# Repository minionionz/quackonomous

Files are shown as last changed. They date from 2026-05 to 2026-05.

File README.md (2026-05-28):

# Hackaburg 2026

# Projekt Quackonomous

---

## Vision

Eine gewöhnliche Gummiente wird zum autonomen Wasserfahrzeug, gesteuert durch Embedded-Logik, navigiert selbstständig oder per Fernsteuerung.

Meilenstein 1: Ente mit Fernbedienung steuern (USB Modul, Steuerelement, ESP now)

Meilenstein 2: Hilfssysteme (Ultraschallsensor, e.g. Hindernis voraus: bremsen)

---

## Thema & Scope

| Bereich | Beschreibung |
| --- | --- |
| Fahrzeug | Gummiente mit Antrieb + Ruder |
| Steuerung | Autonom + manuelle Fernsteuerung |
| Domäne | Embedded Systems / Robotik |
| Hardware | Vollständig vorhanden  |

---

## Phasenplan

| Phase | Fokus | Status |
| --- | --- | --- |
| 1 — Setup | Hardware checken, Rollen verteilen | done |
| 2 — Core | Antrieb + Fernsteuerung |  |
| 3 — Autonomie | Sensorik + Navigation |  |
| 4 — Demo | Test, Pitch, Puffer |  |

---

## Aufgaben

### Phase 1 — Setup

- [x]  Hardware-Inventur: welche Komponenten sind da?
- [ ]  Rollen im Team verteilen
- [x]  Repo + Projektstruktur aufsetzen

### Phase 2 — Core

- [ ]  Antriebstest — Motor + Ruder auf Funktion prüfen
- [ ]  Microcontroller / SBC aufsetzen (Firmware / OS)
- [ ]  Fernsteuerung implementieren (Bluetooth / RF / WLAN)

### Phase 3 — Autonomie

- [ ]  Sensorik einbinden (Ultraschall / Kamera / GPS?)
- [ ]  Autonome Navigationslogik entwickeln
- [ ]  Wassertauglichkeit / Abdichtung prüfen

### Phase 4 — Demo

- [ ]  Demo-Lauf testen
- [ ]  GitHub README schreiben

---

## Team-Rollen

| Rolle | Verantwortung | Person |
| --- | --- | --- |
| Hardware / Mechanik | Antrieb, Verkabelung, Wasserdichtigkeit |  |
| Embedded / Firmware | Microcontroller, Treiber, Low-Level |  |
| Software / Autonomie | Navigationslogik, Sensorauswertung |  |
| Fernsteuerung / Protokoll | Kommunikation, RC-Interface |  |
| Präsentation / Doku | Demo, Pitch, README |  |

---

## Offene Fragen & Risiken

- [ ]  Stromversorgung im Wasser — Akku-Laufzeit?
- [ ]  Latenz bei Fernsteuerung akzeptabel?
- [ ]  Wie wird der Kurs definiert? (GPS-Wegpunkte / Linienverfolgung / Kompass)

---

## Links & Ressourcen

- Hardware-Doku:
- Hackathon-Regeln / Einreichung:

---

## Notizen

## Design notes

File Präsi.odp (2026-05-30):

## Quackonomous

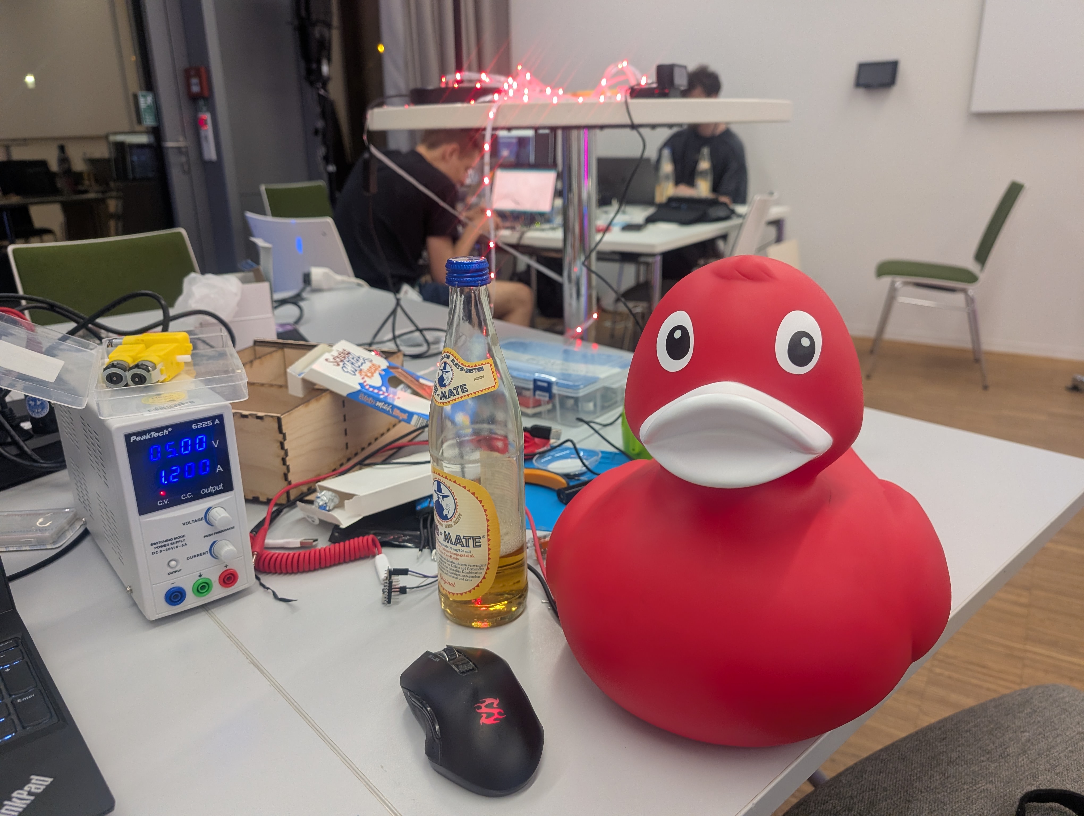
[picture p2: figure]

## Dual Motor Design

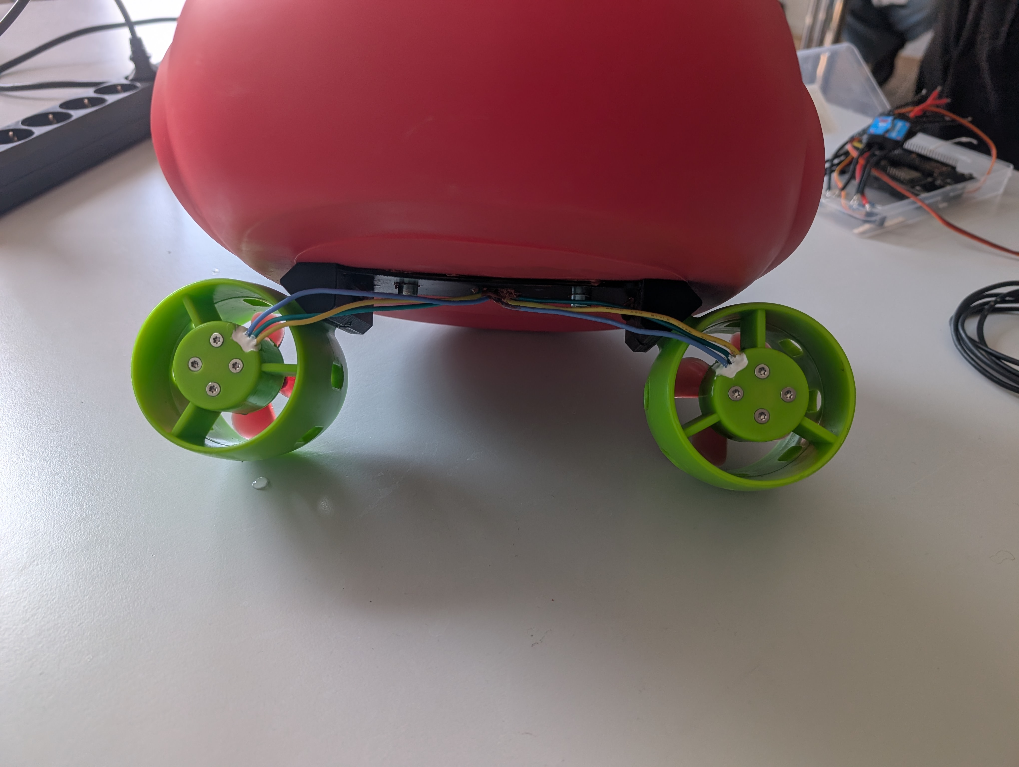
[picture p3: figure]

- Double 30A ESC
- 888W Total Motor Power

## Duck Vision

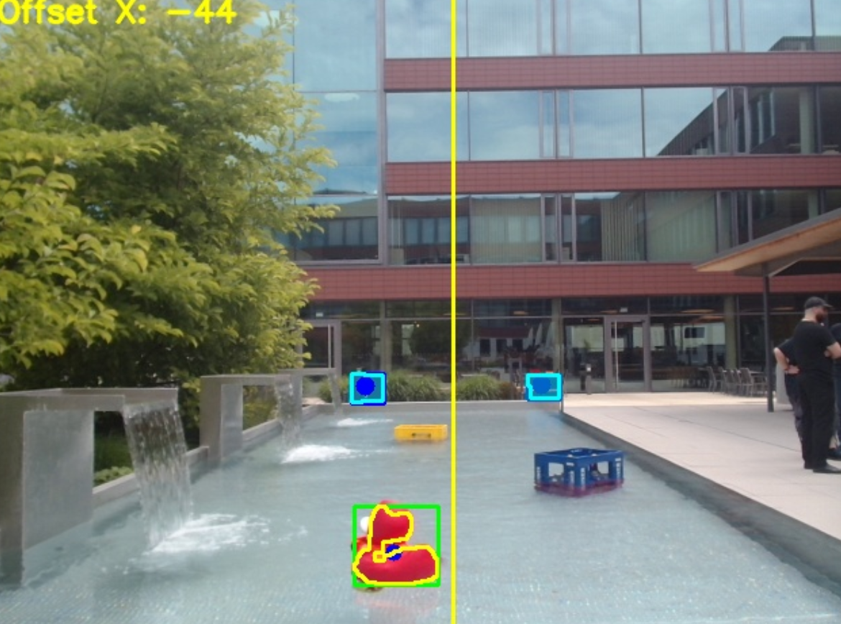
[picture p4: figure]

- Two Target Markers
- Duck Tracking
- Target Determination

## Metric Analytics

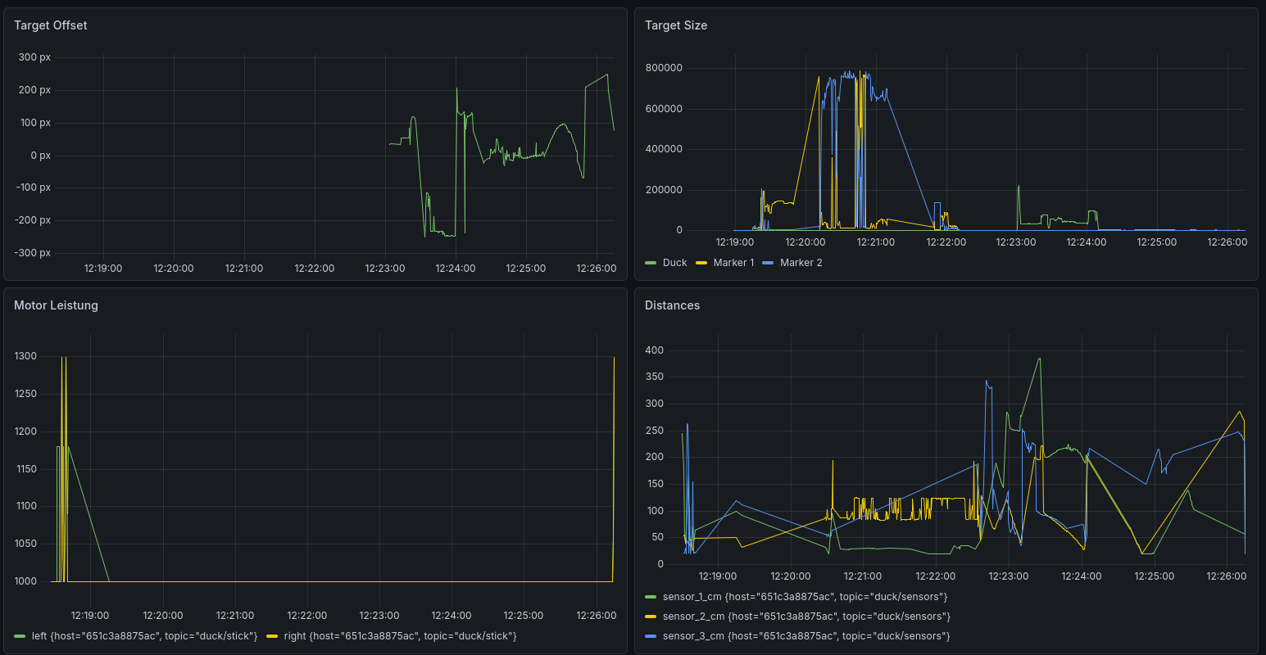
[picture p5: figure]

- Mosqitto MQTT
- Telegraf
- Influxdb
- Grafana

## Ultrasonic Distance Sensors

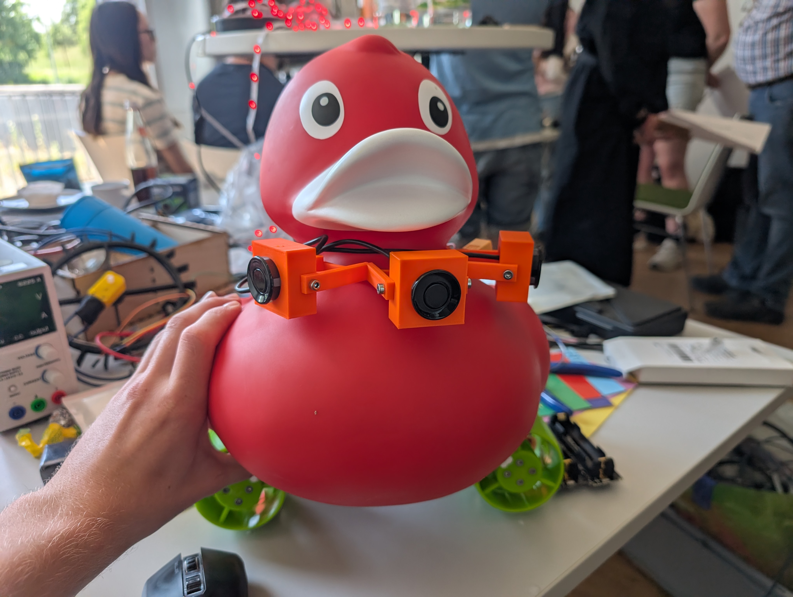
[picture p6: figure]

## Backflip capability

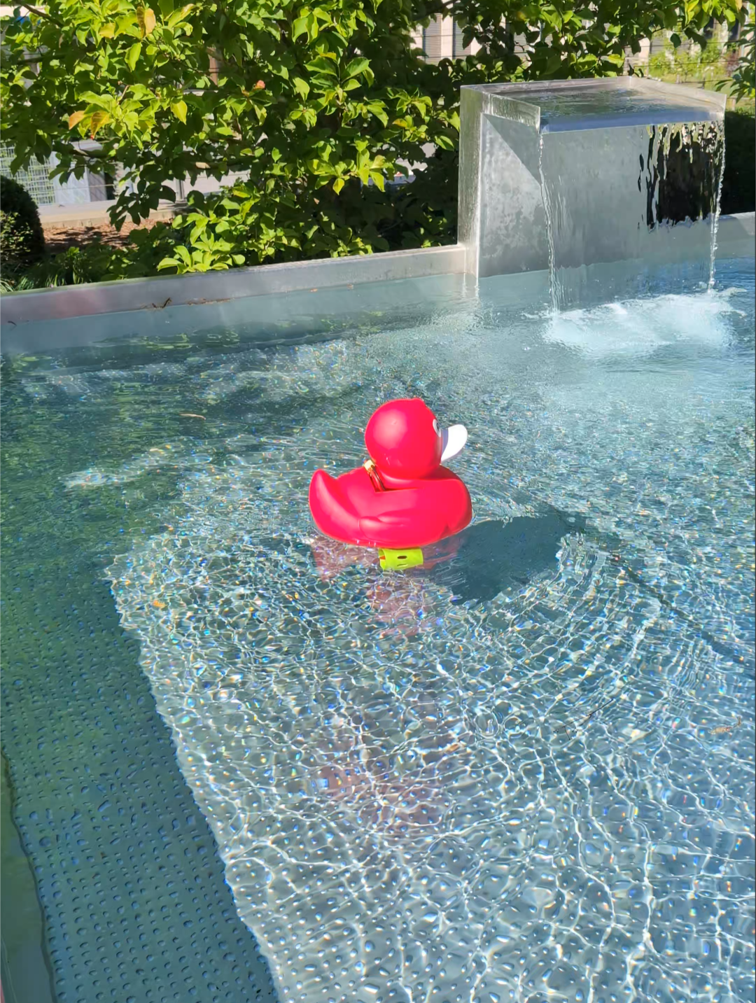
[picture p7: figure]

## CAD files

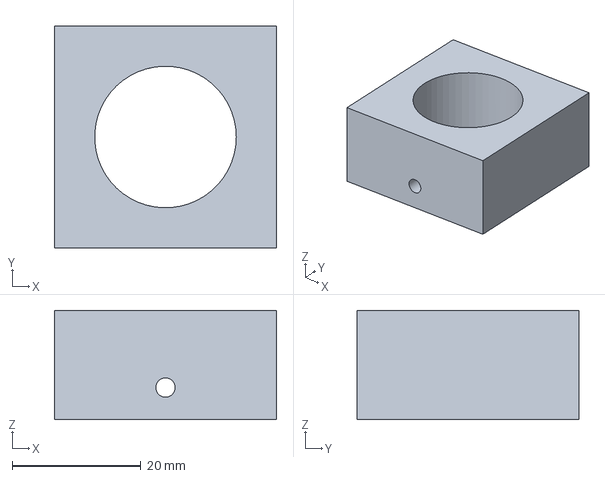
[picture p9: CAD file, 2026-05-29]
3D Teile/Enten Halsband/Halsband.FCStd
34.5 x 34.5 x 17.0 mm

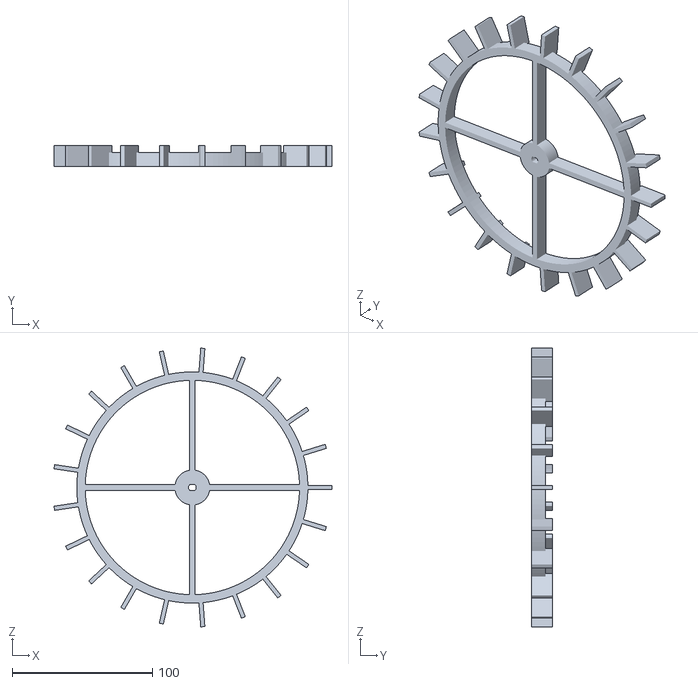
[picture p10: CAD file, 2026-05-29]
3D Teile/Schaufelräder/Schaufelrad.stl
198.5 x 15.0 x 199.0

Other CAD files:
3D Teile/Enten Halsband/Sensor-Halterung.stl
3D Teile/Schaufelräder/Schaufelräder.FCStd
3D Teile/Enten Halsband/Halsband.stl

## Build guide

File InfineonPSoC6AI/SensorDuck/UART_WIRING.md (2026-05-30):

# UART WIRING
## Wiring PSoC6 → ESP32 Feather:
```
┌────────────────────────┬─────────────────┬────────────────────────────────┐
│   CY8CKIT-062S2-AI     │  ESP32 Feather  │              Note              │
│    (Arduino header)    │                 │                                │
├────────────────────────┼─────────────────┼────────────────────────────────┤
│ P9_1 (Arduino D1)      │ Any free RX pin │ PSoC TX → ESP RX               │
│                        │  (e.g. GPIO16)  │                                │
├────────────────────────┼─────────────────┼────────────────────────────────┤
│                        │ Any free TX pin │ PSoC RX ← ESP TX (optional,    │
│ P9_0 (Arduino D0)      │  (e.g. GPIO17)  │ only needed if ESP sends       │
│                        │                 │ commands back)                 │
├────────────────────────┼─────────────────┼────────────────────────────────┤
│ GND                    │ GND             │ Required — common ground       │
└────────────────────────┴─────────────────┴────────────────────────────────┘
```

Both sides are 3.3 V logic so no level shifting needed. On the ESP32 side use Serial2.begin(115200) and read lines with Serial2.readStringUntil('\n'), then parse with ArduinoJson. The "imu":true,"mag":true fields let you skip malformed packets.

## How do I parse this on the ESP32 side?

### platformio.ini
Use ArduinoJson. Add it to Firmware Duck/platformio.ini:
```YAML
lib_deps =
    bblanchon/ArduinoJson@^7
```

### Sketch
Then in your sketch:

```C
#include <Arduino.h>
#include <ArduinoJson.h>

// ── Feather ESP32 (classic HUZZAH32): GPIO16/17 are fine
// ── Feather ESP32 V2: GPIO16 = PSRAM — use something else, e.g. GPIO27/33
#define PSOC_RX_PIN 16
#define PSOC_TX_PIN 17

static char     _rxbuf[256];
static uint16_t _rxpos = 0;

void setup() {
    Serial.begin(115200);

    // Must be called BEFORE begin() — doubles the default RX buffer
    Serial2.setRxBufferSize(512);
    Serial2.begin(115200, SERIAL_8N1, PSOC_RX_PIN, PSOC_TX_PIN);
}

void onSensorLine(const char* line) {
    JsonDocument doc;
    if (deserializeJson(doc, line) != DeserializationError::Ok) {
        Serial.println("bad json");
        return;
    }
    if (!doc["ok"]["imu"] || !doc["ok"]["mag"]) return;

    float heading = doc["mag"]["hdg"];
    float gyro_z  = doc["imu"]["gyro"]["z"];
    // … use values
    Serial.printf("hdg=%.1f  gyro_z=%.2f\n", heading, gyro_z);
}
<<<<<<< Updated upstream
=======

void loop() {
    // Drain everything available this tick — never blocks
    while (Serial2.available()) {
        char c = (char)Serial2.read();

        if (c == '\n') {
            // Strip trailing \r if present
            if (_rxpos > 0 && _rxbuf[_rxpos - 1] == '\r') _rxpos--;
            _rxbuf[_rxpos] = '\0';

            if (_rxpos > 0) onSensorLine(_rxbuf);
            _rxpos = 0;

        } else if (_rxpos < sizeof(_rxbuf) - 1) {
            _rxbuf[_rxpos++] = c;

        } else {
            // Line longer than buffer — discard and resync
            _rxpos = 0;
        }
    }

    // … rest of your loop (motors, ESP-NOW, etc.)
}
>>>>>>> Stashed changes
```

A few things to note:

- readStringUntil('\n') blocks until it sees \n — the PSoC sends \r\n so trim() strips the trailing \r.
- Check doc["ok"] before using values — during the first ~500 ms after boot the sensors may not be ready yet.
- JsonDocument (no size parameter) is ArduinoJson 7. If you're on v6 use StaticJsonDocument<256> doc; instead.
- For steering you'll mostly care about mag.hdg (where are we pointing) and imu.gyro.z (how fast are we turning). The accel and mag field X/Y/Z are there when you want tilt compensation later.

<<<<<<< Updated upstream
## Magnet data hints

### Why does mag.field have X/Y/Z?

The magnetometer measures the full 3D magnetic field vector, not a heading directly. Heading is computed as atan2(field.y, field.x) — but that formula only gives the correct compass bearing when the board is perfectly flat. The moment the duck tilts (waves, acceleration), the answer drifts.

field.z (the vertical dip component) lets the ESP32 do tilt-compensated heading by combining all three magnetic field components with the IMU accelerometer. The formula rotates the magnetic vector out of the tilted frame back into the horizontal plane before computing the angle. Without Z you can't do that.

So the short version: hdg is the fast and easy bearing, fine for calm water. If you want accurate heading while the duck is rocking, the ESP32 can compute a corrected heading from field.x/y/z + imu.accel.x/y/z.
=======
## Thoughts about "Regelung"
❯ Can we use the degree data and its derivative to differentiate degree changes coming from floating on the water from degree changes coming from turning left or right? Is this a good way to differentiate these two kinds of motions or are there better ones (we only want to counteract drifts to the sides while driving and not the usual floating)?

Good question, and the honest answer is: not reliably using those two signals alone. Here's why, and what actually works.

Why heading + turn rate isn't enough

Both drift and intentional turning produce the same signature in those signals — a changing heading and a non-zero turn rate. You could try a threshold ("if turn rate < 3 °/s it's drift, if > 10 °/s it's intentional"), but this breaks whenever:
- You command a slow, gentle correction turn
- A strong current or wind causes fast drift
- Waves make the heading oscillate rapidly at small amplitude

What actually distinguishes them

The real discriminator is whether you commanded the motion. The signal you're missing is the motor/steering output. Once you know that:

┌──────────────────────────┬────────────────────┬────────────────────────────────────────────────┐
│        Situation         │ Commanded steering │            Gyro.z / heading change             │
├──────────────────────────┼────────────────────┼────────────────────────────────────────────────┤
│ Going straight, no drift │ ~zero              │ ~zero                                          │
├──────────────────────────┼────────────────────┼────────────────────────────────────────────────┤
│ Going straight, drifting │ ~zero              │ non-zero ← this is what you want to counteract │
├──────────────────────────┼────────────────────┼────────────────────────────────────────────────┤
│ Intentional turn         │ non-zero           │ non-zero (expected)                            │
├──────────────────────────┼────────────────────┼────────────────────────────────────────────────┤
│ Turn complete, coasting  │ ~zero              │ small residual                                 │
└──────────────────────────┴────────────────────┴────────────────────────────────────────────────┘

Drift is simply unexpected heading change — motion that occurs without a corresponding steering command.

The standard solution: heading hold

Instead of classifying motion, just hold a target heading. This sidesteps the problem entirely:

# Pseudocode on the ESP32 side

```C
target_hdg = None   # set once duck starts straight-line driving

def loop():
    current_hdg = read_psoc_heading()
    joystick_turn = read_joystick_x()

    if joystick_turn != 0:
        # Intentional turn: don't fight it, update target when done
        apply_steering(joystick_turn)
        target_hdg = None  # will re-lock when joystick returns to center

    else:
        if target_hdg is None:
            target_hdg = current_hdg  # lock current heading as target

        # Wrap-corrected error: positive = drifted clockwise, needs left correction
        error = ((target_hdg - current_hdg + 180) % 360) - 180

        if abs(error) > DEAD_ZONE_DEG:   # e.g. 5°
            correction = Kp * error - Kd * gyro_z   # PD controller
            apply_steering(correction)
```

gyro_z from the IMU is the D term here — it damps oscillation so the duck doesn't overshoot and wobble. This is actually the best use of that value; the numerical derivative of heading you're already plotting is the noisier version of the same thing.

Are there better sensors for this?

If you want to be more sophisticated:

- GPS would give you actual lateral displacement (best, but overkill for a pool)
- Optical flow / camera — can detect sideways drift directly from pixel motion
- Accelerometer lateral axis — imu.accel.x (sideways) shows if the duck is being pushed sideways by current; integrating it gives an estimate of lateral velocity. This won't drift-compensate the yaw but tells you why the duck is drifting.

Practical recommendation for the hackathon

The heading-hold PD loop above is the right call. It's ~20 lines on the ESP32, works with the data you're already sending, and doesn't require classifying anything. The wave wobble (high-frequency oscillation in heading) gets filtered out naturally by the dead zone and the D term. What remains and accumulates over time — slow drift — is exactly what the P term corrects.

The compass viewer derivative plot is still useful for tuning: if you see the amber line oscillating while the duck is supposed to go straight, that's wave noise you need to dead-zone out. If it slowly ramps in one direction without a joystick command, that's drift your heading hold will correct.

✻ Sautéed for 52s
>>>>>>> Stashed changes

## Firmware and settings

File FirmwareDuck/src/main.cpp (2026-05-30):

#include <Arduino.h>
#include <WiFi.h>
#include <esp_now.h>
#include <esp_wifi.h>
#include <ESP32Servo.h>
#include <PubSubClient.h>
#include "common.h"

Servo esc_L;
Servo esc_R;
WiFiClient wifiClient;
PubSubClient mqttClient(wifiClient);

const int X_MIN = 0;
const int X_MAX = 4096;
const int Y_MIN = 0;
const int Y_MAX = 4096;

const int MOTOR_MIN = 1000; // Minimaler PWM-Wert für die Motoren = stop
const int MOTOR_MAX = 1600; // Maximaler PWM-Wert für die Motoren

const int X_DEADZONE = 80;  // Toter Bereich um die X-Nullstellung
const int Y_DEADZONE = 80;  // Toter Bereich um die Y-Nullstellung
const int X_NEUTRAL = 1840; // Gemessene X-Nullstellung
const int Y_NEUTRAL = 1880; // Gemessene Y-Nullstellung
const float STEERING_STRENGTH= 0.25; // WARNING: This is added to the MOTOR_MAX value!

const int Motor_R = 16;
const int Motor_L = 4;
const uint8_t DEFAULT_ESPNOW_CHANNEL = 1;

const char *WIFI_SSID = "Ducknet";
const char *WIFI_PASSWORD = "Ducknet123";

const char *MQTT_BROKER = "10.42.0.1";
const uint16_t MQTT_PORT = 1883;
const char *MQTT_CLIENT_ID = "duck-firmware";
const char *MQTT_STATUS_TOPIC = "duck/status";
const char *MQTT_STICK_TOPIC = "duck/stick";
const char *MQTT_QUACK_TOPIC = "duck/quack";
const char *MQTT_COMMAND_TOPIC = "duck/cmd";
const char *MQTT_SENSORS_TOPIC = "duck/sensors";

const int SENSOR_1_TRIG = 17;
const int SENSOR_1_ECHO = 5;
const int SENSOR_2_TRIG = 18;
const int SENSOR_2_ECHO = 19;
const int SENSOR_3_TRIG = 21;
const int SENSOR_3_ECHO = 22;

const unsigned long SENSOR_READ_INTERVAL_MS = 200;
const unsigned long SENSOR_GAP_MS = 40;

unsigned long lastMqttReconnectAttempt = 0;
unsigned long lastSensorReadMs = 0;
unsigned long lastPacketReceivedMs = 0;
unsigned long lastStickPacketReceivedMs = 0;
bool motorsStoppedByTimeout = false;
const unsigned long PACKET_TIMEOUT_MS = 20000;

static uint8_t getEspNowChannel()
{
  if (WiFi.status() == WL_CONNECTED)
  {
    return WiFi.channel();
  }

  return DEFAULT_ESPNOW_CHANNEL;
}

static void applyWifiChannel(uint8_t channel)
{
  esp_wifi_set_channel(channel, WIFI_SECOND_CHAN_NONE);
}

static void publishState(const char *topic, const String &payload)
{
  if (mqttClient.connected())
  {
    mqttClient.publish(topic, payload.c_str(), true);
  }
}

static float readDistanceCm(int trigPin, int echoPin)
{
  digitalWrite(trigPin, LOW);
  delayMicroseconds(2);
  digitalWrite(trigPin, HIGH);
  delayMicroseconds(10);
  digitalWrite(trigPin, LOW);

  const unsigned long duration = pulseIn(echoPin, HIGH, 30000);
  if (duration == 0)
  {
    return -1.0f;
  }

  return static_cast<float>(duration) * 0.0343f * 0.5f;
}

static void appendDistanceJsonValue(String &json, float distanceCm)
{
  if (distanceCm < 0.0f)
  {
    json += "null";
  }
  else
  {
    json += String(distanceCm, 1);
  }
}

static void setupSensorPins()
{
  pinMode(SENSOR_1_TRIG, OUTPUT);
  pinMode(SENSOR_1_ECHO, INPUT);
  pinMode(SENSOR_2_TRIG, OUTPUT);
  pinMode(SENSOR_2_ECHO, INPUT);
  pinMode(SENSOR_3_TRIG, OUTPUT);
  pinMode(SENSOR_3_ECHO, INPUT);

  digitalWrite(SENSOR_1_TRIG, LOW);
  digitalWrite(SENSOR_2_TRIG, LOW);
  digitalWrite(SENSOR_3_TRIG, LOW);
}

static void readAndPublishSensors()
{
  const float distance1 = readDistanceCm(SENSOR_1_TRIG, SENSOR_1_ECHO);
  delay(SENSOR_GAP_MS);
  const float distance2 = readDistanceCm(SENSOR_2_TRIG, SENSOR_2_ECHO);
  delay(SENSOR_GAP_MS);
  const float distance3 = readDistanceCm(SENSOR_3_TRIG, SENSOR_3_ECHO);

  String payload = "{";
  payload += "\"sensor_1_cm\":";
  appendDistanceJsonValue(payload, distance1);
  payload += ",\"sensor_2_cm\":";
  appendDistanceJsonValue(payload, distance2);
  payload += ",\"sensor_3_cm\":";
  appendDistanceJsonValue(payload, distance3);
  payload += "}";

  // Serial.print("[SENSORS] ");
  // Serial.println(payload);

  publishState(MQTT_SENSORS_TOPIC, payload);
}

static void mqttCallback(char *topic, byte *payload, unsigned int length)
{
  Serial.print("[MQTT] Nachricht auf ");
  Serial.print(topic);
  Serial.print(": ");

  String message;
  for (unsigned int i = 0; i < length; i++)
  {
    message += static_cast<char>(payload[i]);
  }

  Serial.println(message);

  if (strcmp(topic, MQTT_COMMAND_TOPIC) == 0)
  {
    if (message == "stop")
    {
      esc_L.writeMicroseconds(MOTOR_MIN);
      esc_R.writeMicroseconds(MOTOR_MIN);
      publishState(MQTT_STATUS_TOPIC, "motors stopped");
    }
  }
}

static void connectToWiFi()
{
  if (WiFi.status() == WL_CONNECTED)
  {
    return;
  }

  Serial.print("Verbinde mit WiFi ");
  Serial.println(WIFI_SSID);
  WiFi.setSleep(false);
  WiFi.mode(WIFI_STA);
  WiFi.begin(WIFI_SSID, WIFI_PASSWORD);

  unsigned long start = millis();
  while (WiFi.status() != WL_CONNECTED && millis() - start < 15000)
  {
    delay(500);
    Serial.print('.');
  }
  Serial.println();

  if (WiFi.status() == WL_CONNECTED)
  {
    applyWifiChannel(getEspNowChannel());
    Serial.print("WiFi verbunden, IP: ");
    Serial.println(WiFi.localIP());
    Serial.print("Aktiver Kanal: ");
    Serial.println(WiFi.channel());
  }
  else
  {
    Serial.println("WiFi Verbindungsfehler");
  }
}

static void connectToMqtt()
{
  if (WiFi.status() != WL_CONNECTED)
  {
    return;
  }

  if (mqttClient.connected())
  {
    return;
  }

  const unsigned long now = millis();
  if (now - lastMqttReconnectAttempt < 5000)
  {
    return;
  }
  lastMqttReconnectAttempt = now;

  Serial.print("Verbinde mit MQTT Broker ");
  Serial.print(MQTT_BROKER);
  Serial.print(":");
  Serial.println(MQTT_PORT);

  mqttClient.setServer(MQTT_BROKER, MQTT_PORT);
  mqttClient.setCallback(mqttCallback);

  if (mqttClient.connect(MQTT_CLIENT_ID))
  {
    Serial.println("MQTT verbunden");
    mqttClient.subscribe(MQTT_COMMAND_TOPIC);
    publishState(MQTT_STATUS_TOPIC, "online");
  }
  else
  {
    Serial.print("MQTT Verbindungsfehler, rc=");
    Serial.println(mqttClient.state());
  }
}

static int mapToEsc(int value, int inMin, int inMax)
{
  return constrain(map(value, inMin, inMax, MOTOR_MIN, MOTOR_MAX), MOTOR_MIN, MOTOR_MAX);
}


float currentMotorLeft = 0;
float currentMotorRight = 0;
const float SECS_ZEROTOMAX = 1.5;
const float E = 5; // Acceleration curve.

const int TIMEOUT_STOP_AFTER_RECV = 1000;
float accelerating_for = 0.0;
int time_last_received;

const float DIFF_BUFFER = 0.01;

// We don't have floating points, so this is for mapping like 0.0 to 1.0.
#define FULL 1000000
#define bool_str(x) (x > 0)? "✅":"❌" // For debug printing
float prev_millis = 0;
static void driveEscFromStick(const StickData &stickData)
{
  Serial.println();
  unsigned long mills = millis();
  // For calculating acceleration based on time
  float delta = (mills - prev_millis) / 1000.0;
  prev_millis = mills;
  accelerating_for += delta;

  // Reset motors when not receiving anything for some time
  // THIS DOES NOT WORK THE WAY WE THING IT DOES. THIS GETS EXECUTED ONLY ON THE PACKAGE AFTER A LONG PAUSE.
  if (mills - time_last_received > TIMEOUT_STOP_AFTER_RECV) {
    Serial.println("Didn't receive a package since a long time. Resetting acceleration.");
    accelerating_for = 0;
  }
  time_last_received = mills;

  // TODO: Gegenlenken wenn man aufhört, rechts zu lenken.
  const int x = stickData.x;
  const int y = stickData.y;

  // Values sent by the remote. Ranges from 0 to 1
  float goalMotorLeft  = 0;
  float goalMotorRight = 0;

  /* Map data to motor direction */
  bool is_going_left, is_going_right, is_going_forward;
  float throttle = 0;
  if (y > Y_NEUTRAL + Y_DEADZONE) {
    throttle      = constrain(map(y, Y_NEUTRAL + Y_DEADZONE, Y_MAX, 0, FULL), 0, FULL) / (float)FULL;
    is_going_forward = throttle > DIFF_BUFFER;
  }
  float steeringDelta = 0;
  Serial.printf("X: %d | XMAX: %d | MAP: %f\n", x, X_MAX, map(x, X_NEUTRAL + X_DEADZONE, X_MAX, 0, FULL) / (float) FULL);
  // Driving left: goalMotorRight>LEAST
  if (x < X_NEUTRAL - X_DEADZONE) {
    steeringDelta = STEERING_STRENGTH * (constrain(map(x, X_NEUTRAL - X_DEADZONE, X_MIN, 0, FULL), 0, FULL) / (float) FULL);
    is_going_left = steeringDelta > DIFF_BUFFER;
  }
  // Driving right: goalMotorLeft>LEAST
  else if (x > X_NEUTRAL + X_DEADZONE) {
    // Needs a negative sign for some reason
    steeringDelta  = STEERING_STRENGTH * (constrain(-map(x, X_NEUTRAL + X_DEADZONE, X_MAX, 0, FULL), 0, FULL) / (float) FULL);
    is_going_right = steeringDelta > DIFF_BUFFER;
  }
  Serial.printf("THROT: %f | DELTA: %f\n", throttle, steeringDelta);

  // // EXPERIMENTAL steering stabilizer. 
  // if (was_going_left && not is_going_left && not is_going_right) {
  //   steeringDelta -= - STEERING_STRENGTH * 0.5;
  // } else if (was_going_right && not is_going_right && not is_going_left) {
  //   steeringDelta += STEERING_STRENGTH * 0.5;
  // }

  // Accelerating
  // from 0 to 1.
  float accelProgress = constrain(pow(E, (accelerating_for / SECS_ZEROTOMAX) - 1), 0.0, throttle);
  Serial.printf("GOING: %f / %f | PROGRESS: %f\n", accelerating_for, SECS_ZEROTOMAX, accelProgress);

  // The accelerated base speed + the full rotating speed
  float real_throttle = constrain(accelProgress, 0, throttle);
  // Add left/right direction to throttle
  // !!! So this might go _over_ the MOTOR_MAX value !!!

  if (!is_going_forward) 
    accelerating_for = 0;

  float steering_bias = 0;
  if (!is_going_forward && (is_going_left || is_going_right))
    steering_bias = STEERING_STRENGTH;

  if (is_going_right)
    steeringDelta *= (-1);

  goalMotorLeft  = steering_bias + real_throttle - steeringDelta;
  goalMotorRight = steering_bias + real_throttle + steeringDelta;

  Serial.printf("Is going: Forward: %s %f | Left: %s %f | Right: %s %f\n",
      bool_str(is_going_forward), real_throttle,
      bool_str(is_going_left),  goalMotorLeft,
      bool_str(is_going_right), goalMotorRight
  );

  currentMotorLeft  = constrain(goalMotorLeft, 0, 1.0 + STEERING_STRENGTH);
  currentMotorRight = constrain(goalMotorRight, 0, 1.0 + STEERING_STRENGTH);
  Serial.printf("Left Motor going at: %f %%  |\t  ", currentMotorLeft);
  Serial.printf("Right Motor going at: %f %%\n", currentMotorRight);

  esc_L.writeMicroseconds(MOTOR_MIN + currentMotorLeft  * (MOTOR_MAX - MOTOR_MIN));
  esc_R.writeMicroseconds(MOTOR_MIN + currentMotorRight * (MOTOR_MAX - MOTOR_MIN));

  bool was_going_forward = is_going_forward;
  bool was_going_left    = is_going_left;
  bool was_going_right   = is_going_right;

  Serial.printf("WAS going: Forward: %s | Left: %s | Right: %s \n",
      bool_str(was_going_forward),
      bool_str(was_going_left),
      bool_str(was_going_right)
  );

  if (mqttClient.connected())
  {
    String payload = String("{\"x\":") + x + String(",\"y\":") + y + String(",\"left\":") + goalMotorLeft + String(",\"right\":") + goalMotorRight + String("}");
    publishState(MQTT_STICK_TOPIC, payload);
  }
}

// Callback-Funktion, die automatisch aufgerufen wird, wenn eine ESP-NOW-Nachricht empfangen wird
// Sie erhält die MAC-Adresse des Senders und die empfangenen Daten.
void OnDataRecv(const uint8_t *mac_addr, const uint8_t *data, int len)
{
  // MAC address des Senders ausgeben
  Serial.print("[MSG] From: ");
  print_mac_address(mac_addr);

  Serial.print(" | Message: ");
  if (len >= static_cast<int>(sizeof(Message)))
  {
    Message message;
    memcpy(&message, data, sizeof(Message));

    Serial.print(msg_type_name(message.msg_type));

    if (message.msg_type == STICK_DATA)
    {
      Serial.print(" x=");
      Serial.print(message.data.stick_data.x);
      Serial.print(", y=");
      Serial.print(message.data.stick_data.y);

      driveEscFromStick(message.data.stick_data);
      lastPacketReceivedMs = millis();
      lastStickPacketReceivedMs = lastPacketReceivedMs;
      // if (motorsStoppedByTimeout)
      // {
      //   motorsStoppedByTimeout = false;
      //   publishState(MQTT_STATUS_TOPIC, "motors resumed");
      // }
    }
    else if (message.msg_type == QUACK)
    {
      Serial.print(" i=");
      Serial.print(message.data.i);

      if (mqttClient.connected())
      {
        publishState(MQTT_QUACK_TOPIC, String(message.data.i));
      }
      lastPacketReceivedMs = millis();
    }
  }
  else
  {
    Serial.print("ungültige Länge (");
    Serial.print(len);
    Serial.print(")");
  }

  Serial.print(" ");
  Serial.println();
}

// Initialisierung des ESP32
void setup()
{
  Serial.begin(115200);
  WiFi.setSleep(false);

  setupSensorPins();

  connectToWiFi();
  delay(2000); // Delay for monitor

  // Zur Information: Die MAC-Adresse des ESP32 wird hier ausgegeben,
  // damit du sie für den Sender verwenden kannst
  Serial.print("Empfänger MAC: ");
  Serial.println(WiFi.macAddress());

  // Initialisiere ESP-NOW
  applyWifiChannel(getEspNowChannel());
  if (esp_now_init() != ESP_OK)
  {
    Serial.println("ESP-NOW Fehler");
    while (true)
      delay(1000);
  }

  // Registriere die Callback-Funktion, die aufgerufen wird, wenn Daten empfangen werden
  // OnDataRecv wird automatisch aufgerufen, wenn eine ESP-NOW-Nachricht ankommt
  esp_now_register_recv_cb(OnDataRecv);

  // Bestätige, dass der Empfänger bereit ist
  Serial.println("Empfänger bereit");

  esc_L.attach(Motor_L, 1000, 2000);
  esc_R.attach(Motor_R, 1000, 2000);

  esc_L.writeMicroseconds(1000);
  esc_R.writeMicroseconds(1000);

  mqttClient.setBufferSize(256);
  connectToMqtt();

  delay(3000);
}

void loop()
{
  if (WiFi.status() != WL_CONNECTED)
  {
    connectToWiFi();
  }
  else
  {
    applyWifiChannel(getEspNowChannel());
  }

  if (!mqttClient.connected())
  {
    connectToMqtt();
  }
  else
  {
    mqttClient.loop();
  }

  const unsigned long now = millis();
  if (now - lastSensorReadMs >= SENSOR_READ_INTERVAL_MS)
  {
    lastSensorReadMs = now;
    readAndPublishSensors();
  }

  // // Motoren stoppen, wenn seit PACKET_TIMEOUT_MS keine Fahrdaten mehr kamen
  // if (lastStickPacketReceivedMs != 0 && (now - lastStickPacketReceivedMs > PACKET_TIMEOUT_MS))
  // {
  //   if (!motorsStoppedByTimeout)
  //   {
  //     esc_L.writeMicroseconds(MOTOR_MIN);
  //     esc_R.writeMicroseconds(MOTOR_MIN);
  //     motorsStoppedByTimeout = true;
  //     publishState(MQTT_STATUS_TOPIC, "motors timeout");
  //   }
  // }

  delay(10);
}

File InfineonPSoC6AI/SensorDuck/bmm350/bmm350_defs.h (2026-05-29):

/**
* Copyright (c) 2023 Bosch Sensortec GmbH. All rights reserved.
*
* BSD-3-Clause
*
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
* 1. Redistributions of source code must retain the above copyright
*    notice, this list of conditions and the following disclaimer.
*
* 2. Redistributions in binary form must reproduce the above copyright
*    notice, this list of conditions and the following disclaimer in the
*    documentation and/or other materials provided with the distribution.
*
* 3. Neither the name of the copyright holder nor the names of its
*    contributors may be used to endorse or promote products derived from
*    this software without specific prior written permission.
*
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
* @file       bmm350_defs.h
* @date       2023-05-26
* @version    v1.4.0
*
*/

#ifndef _BMM350_DEFS_H
#define _BMM350_DEFS_H

/*************************** Header files *******************************/

#ifdef __KERNEL__


#else
#include <stdint.h>
#include <stddef.h>
#endif

/***************************** Common Macros *****************************/

#ifdef __KERNEL__
#if !defined(UINT8_C) && !defined(INT8_C)
#define INT8_C(x)    S8_C(x)
#define UINT8_C(x)   U8_C(x)
#endif

#if !defined(UINT16_C) && !defined(INT16_C)
#define INT16_C(x)   S16_C(x)
#define UINT16_C(x)  U16_C(x)
#endif

#if !defined(INT32_C) && !defined(UINT32_C)
#define INT32_C(x)   S32_C(x)
#define UINT32_C(x)  U32_C(x)
#endif

#if !defined(INT64_C) && !defined(UINT64_C)
#define INT64_C(x)   S64_C(x)
#define UINT64_C(x)  U64_C(x)
#endif
#endif

/*! C standard macros */
#ifndef NULL
#ifdef __cplusplus
#define NULL         0
#else
#define NULL         ((void *) 0)
#endif
#endif

/******************************************************************************/
/*! @name        Compiler switch macros Definitions                           */
/******************************************************************************/

/************************* General Macro definitions ***************************/

/* Macro to SET and GET BITS of a register*/
#define BMM350_SET_BITS(reg_data, bitname, data) \
    ((reg_data & ~(bitname##_MSK)) | \
     ((data << bitname##_POS) & bitname##_MSK))

#define BMM350_GET_BITS(reg_data, bitname)          ((reg_data & (bitname##_MSK)) >> (bitname##_POS))

#define BMM350_GET_BITS_POS_0(reg_data, bitname)    (reg_data & (bitname##_MSK))

#define BMM350_SET_BITS_POS_0(reg_data, bitname, data) \
    ((reg_data & ~(bitname##_MSK)) | \
     (data & bitname##_MSK))

#ifndef BMM350_INTF_RET_TYPE
#define BMM350_INTF_RET_TYPE                        int8_t
#endif

#define UNUSED(x) (void)(x)

/*! Chip id of BMM350 */
#define BMM350_CHIP_ID                              UINT8_C(0x33)

/*! Variant ID of BMM350 */
#define BMM350_MIN_VAR                              UINT8_C(0x10)

/************************* Sensor interface success code **************************/
#define BMM350_INTF_RET_SUCCESS                     INT8_C(0)

/************************* API success code **************************/
#define BMM350_OK                                   INT8_C(0)

/* API error codes */
#define BMM350_E_NULL_PTR                           INT8_C(-1)
#define BMM350_E_COM_FAIL                           INT8_C(-2)
#define BMM350_E_DEV_NOT_FOUND                      INT8_C(-3)
#define BMM350_E_INVALID_CONFIG                     INT8_C(-4)
#define BMM350_E_BAD_PAD_DRIVE                      INT8_C(-5)
#define BMM350_E_RESET_UNFINISHED                   INT8_C(-6)
#define BMM350_E_INVALID_INPUT                      INT8_C(-7)
#define BMM350_E_SELF_TEST_INVALID_AXIS             INT8_C(-8)
#define BMM350_E_OTP_BOOT                           INT8_C(-9)
#define BMM350_E_OTP_PAGE_RD                        INT8_C(-10)
#define BMM350_E_OTP_PAGE_PRG                       INT8_C(-11)
#define BMM350_E_OTP_SIGN                           INT8_C(-12)
#define BMM350_E_OTP_INV_CMD                        INT8_C(-13)
#define BMM350_E_OTP_UNDEFINED                      INT8_C(-14)
#define BMM350_E_ALL_AXIS_DISABLED                  INT8_C(-15)
#define BMM350_E_PMU_CMD_VALUE                      INT8_C(-16)

#define BMM350_NO_ERROR                             UINT8_C(0)

/************************* Sensor delay time settings in microseconds **************************/
#define BMM350_SOFT_RESET_DELAY                     UINT32_C(24000)
#define BMM350_MAGNETIC_RESET_DELAY                 UINT32_C(40000)
#define BMM350_START_UP_TIME_FROM_POR               UINT32_C(3000)

#define BMM350_GOTO_SUSPEND_DELAY                   UINT32_C(6000)
#define BMM350_SUSPEND_TO_NORMAL_DELAY              UINT32_C(38000)

#define BMM350_SUS_TO_FORCEDMODE_NO_AVG_DELAY       UINT32_C(15000)
#define BMM350_SUS_TO_FORCEDMODE_AVG_2_DELAY        UINT32_C(17000)
#define BMM350_SUS_TO_FORCEDMODE_AVG_4_DELAY        UINT32_C(20000)
#define BMM350_SUS_TO_FORCEDMODE_AVG_8_DELAY        UINT32_C(28000)
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

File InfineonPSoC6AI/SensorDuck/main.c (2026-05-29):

/*******************************************************************************
 * main.c — SensorDuck JSON telemetry
 *
 * Reads BMI270 (accel + gyro) and BMM350 (magnetometer + heading) and sends
 * one JSON line every 100 ms on two UARTs:
 *
 *   ESP32 UART  P9_1 TX → ESP32 RX          115200 baud
 *               P9_0 RX ← ESP32 TX
 *               GND     → ESP32 GND          (mandatory!)
 *
 *   Debug UART  KitProg3 USB                 115200 baud  (mirrors ESP32 stream)
 *
 * JSON format (one line, \r\n terminated):
 * {
 *   "t"  : ms,          // uptime in milliseconds (wraps at ~49 days)
 *   "imu": {
 *     "accel": {        // linear acceleration from BMI270
 *       "x": mg,        // +X = board right,   -X = board left   (1 g ≈ 9810 mg)
 *       "y": mg,        // +Y = board forward, -Y = board back
 *       "z": mg         // +Z = board up,      -Z = board down   (gravity ≈ +9810 mg when flat)
 *     },
 *     "gyro": {         // angular rate from BMI270
 *       "x": dps,       // roll  rate (right-hand rule around X axis)
 *       "y": dps,       // pitch rate
 *       "z": dps        // yaw   rate — duck turning left/right
 *     }
 *   },
 *   "mag": {
 *     "hdg": deg,       // compass heading 0–360° (0 = magnetic north, 90 = east)
 *                       // derived from atan2(field.y, field.x) — valid only when board is flat
 *     "field": {        // raw magnetic field vector from BMM350, unit: µT
 *       "x": uT,        // horizontal east–west component  (used for heading)
 *       "y": uT,        // horizontal north–south component (used for heading)
 *       "z": uT         // vertical dip component — NOT used for heading, but sending
 *                       // it lets the ESP32 do tilt-compensated heading by combining
 *                       // field.x/y/z with the IMU accel to correct for board tilt
 *     }
 *   },
 *   "ok": {
 *     "imu": bool,      // false if BMI270 did not initialise or read failed
 *     "mag": bool       // false if BMM350 did not initialise or read failed
 *   }
 * }
 *
 * Target : CY8CKIT-062S2-AI  (TARGET=APP_CY8CKIT-062S2-AI)
 * Build  : make program
 *******************************************************************************/

#include "cyhal.h"
#include "cybsp.h"
#include "cy_retarget_io.h"
#include "bmm350_iface.h"
#include <math.h>
#include <stdio.h>
#include <string.h>

/* ============================================================================
 * Configuration
 * ============================================================================ */
#define SENSOR_I2C_SCL    CYBSP_I2C_SCL   /* P0_2 */
#define SENSOR_I2C_SDA    CYBSP_I2C_SDA   /* P0_3 */
#define SENSOR_I2C_FREQ   400000U

/* UART to Duck ESP32 (Arduino header D0/D1) */
#define ESP_UART_TX       P9_1            /* board TX  →  ESP32 RX */
#define ESP_UART_RX       P9_0            /* board RX  ←  ESP32 TX */
#define ESP_UART_BAUD     115200U

#define SEND_INTERVAL_MS  100U            /* 10 Hz */

/* ============================================================================
 * BMI270 register map  (I2C 0x68)
 * ============================================================================ */
#define BMI270_ADDR             0x68U
#define BMI270_REG_CHIP_ID      0x00U
#define BMI270_CHIP_ID_VAL      0x24U
#define BMI270_REG_INTERNAL_STS 0x21U
#define BMI270_REG_ACC_X_LSB    0x0CU    /* 6 bytes: ax_l ax_h ay_l ay_h az_l az_h */
#define BMI270_REG_GYR_X_LSB    0x12U    /* 6 bytes: gx_l gx_h gy_l gy_h gz_l gz_h */
#define BMI270_REG_ACCEL_CONF   0x40U
#define BMI270_REG_ACCEL_RANGE  0x41U    /* 0x03 = ±16 g  →  2048 LSB/g */
#define BMI270_REG_GYR_CONF     0x42U
#define BMI270_REG_GYR_RANGE    0x43U    /* 0x00 = ±2000 dps  →  16.384 LSB/dps */
#define BMI270_REG_PWR_CONF     0x7CU
#define BMI270_REG_PWR_CTRL     0x7DU
#define BMI270_REG_CMD          0x7EU
#define BMI270_CMD_SOFTRESET    0xB6U
#define BMI270_REG_INIT_CTRL    0x59U
#define BMI270_REG_INIT_ADDR_0  0x5BU
#define BMI270_REG_INIT_ADDR_1  0x5CU
#define BMI270_REG_INIT_DATA    0x5EU
#define BMI270_CONFIG_CHUNK     64U

#define BMI270_LOAD_CONFIG_BLOB
#ifdef BMI270_LOAD_CONFIG_BLOB
#include "bmi270_config.h"
#endif

/* ============================================================================
 * HAL objects
 * ============================================================================ */
static cyhal_i2c_t  g_i2c;
static cyhal_uart_t g_esp_uart;

static bool bmi270_ok   = false;
static bool bmm350_ok   = false;
static bool esp_uart_ok = false;

/* ============================================================================
 * I2C helpers
 * ============================================================================ */
static cy_rslt_t i2c_write_reg(uint8_t dev, uint8_t reg, uint8_t val)
{
    uint8_t buf[2] = { reg, val };
    return cyhal_i2c_master_write(&g_i2c, dev, buf, 2, 20, true);
}

static cy_rslt_t i2c_read_regs(uint8_t dev, uint8_t reg,
                                uint8_t *out, uint16_t len)
{
    cy_rslt_t rc = cyhal_i2c_master_write(&g_i2c, dev, &reg, 1, 20, false);
    if (rc != CY_RSLT_SUCCESS) return rc;
    return cyhal_i2c_master_read(&g_i2c, dev, out, len, 20, true);
}

/* ============================================================================
 * BMI270 init
 * ============================================================================ */
#ifdef BMI270_LOAD_CONFIG_BLOB
static void bmi270_load_config_blob(void)
{
    i2c_write_reg(BMI270_ADDR, BMI270_REG_INIT_CTRL, 0x00U);
    cyhal_system_delay_ms(1);

    uint8_t buf[BMI270_CONFIG_CHUNK + 1];
    for (size_t i = 0; i < bmi270_config_size; i += BMI270_CONFIG_CHUNK) {
        uint16_t word_addr = (uint16_t)(i >> 1);
        i2c_write_reg(BMI270_ADDR, BMI270_REG_INIT_ADDR_0,
                      (uint8_t)(word_addr & 0x0FU));
        i2c_write_reg(BMI270_ADDR, BMI270_REG_INIT_ADDR_1,
                      (uint8_t)((word_addr >> 4) & 0xFFU));
        size_t chunk = (i + BMI270_CONFIG_CHUNK <= bmi270_config_size)
                       ? BMI270_CONFIG_CHUNK : (bmi270_config_size - i);
        buf[0] = BMI270_REG_INIT_DATA;
        memcpy(&buf[1], &bmi270_config_file[i], chunk);
        cyhal_i2c_master_write(&g_i2c, BMI270_ADDR, buf,
                               (uint16_t)(chunk + 1), 100, true);
    }
    i2c_write_reg(BMI270_ADDR, BMI270_REG_INIT_CTRL, 0x01U);
    cyhal_system_delay_ms(150);
}
#endif /* BMI270_LOAD_CONFIG_BLOB */

static void bmi270_init(void)
{
    uint8_t id = 0;
    i2c_write_reg(BMI270_ADDR, BMI270_REG_CMD, BMI270_CMD_SOFTRESET);
    cyhal_system_delay_ms(200);

    if (i2c_read_regs(BMI270_ADDR, BMI270_REG_CHIP_ID, &id, 1) != CY_RSLT_SUCCESS
            || id != BMI270_CHIP_ID_VAL) {
        printf("[IMU] BMI270: init failed (id=0x%02X)\r\n", id);
        return;
    }

    i2c_write_reg(BMI270_ADDR, BMI270_REG_PWR_CONF, 0x00U);
    cyhal_system_delay_ms(1);
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

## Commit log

2026-05-28 First sensor test for the ultrasonic sensor in combination with ESP-WROOM-02
2026-05-29 Add Wheel Drive 3d Models
    [Halsband.FCStd, Halsband.stl, Schaufelrad.stl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]
2026-05-29 Add simple ESC Test programm
2026-05-29 Make esp_now work from 8266 to esp32
2026-05-29 Rewrite remote for supermini ESP32-C3
2026-05-29 implement remote motor controll
2026-05-29 Rewrite firmware for remote to better switch between esp types
    Used pio envs
2026-05-29 limit max Duck power drasticly
2026-05-29 Fix sending on esp32
    [main.cpp]
2026-05-29 Fix output and direction
    [main.cpp]
2026-05-29 Added current implementation of SensorDuck project sending sensor data structured as json from the Infineon PSoC6AI to the Firmware Duck ESP32 over UART (if connected correctly). Also, mirrors to USB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
    [bmm350.c, bmm350_defs.h, bmm350_iface.c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]
2026-05-30 Added magnet data implementation hints
2026-05-30 Improved UART interaction markdown, updated requirements.txt
2026-05-30 remove ESP32-C3 from platformio.ini
2026-05-30 Fix steering
